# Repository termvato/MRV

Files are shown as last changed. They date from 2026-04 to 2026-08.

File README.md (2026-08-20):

# Monopedal Reconnaissance Vehicle (MRV)

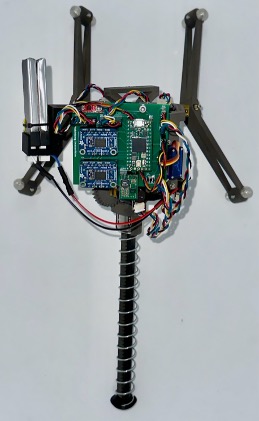
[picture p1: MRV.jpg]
MRV


A spring-loaded monopedal hopping robot stabilised by dual-axis reaction wheels, designed as a proof of concept for low-gravity exploration. Please read Dissertation.pdf for in depth development.

Developed as a BEng Mechanical Engineering thesis at the University of Warwick (ES327), supervised by Dr. Chris Purssell. Inspired by UC Berkeley's [SALTO](https://doi.org/10.1126/scirobotics.aag2048).

https://github.com/user-attachments/assets/57d9b59d-b111-4331-9489-9ee04b618cc3

https://github.com/user-attachments/assets/74c44a05-26f5-4240-8d7b-2275602fc39d

---

## Specifications

| Parameter | Value |
|---|---|
| Mass | 360 g |
| Jump height | 41.1 cm ± 1.2 cm |
| Release efficiency | 67.8% |
| Max recovery angle | 12.7° (bang-bang, full extension) |
| Energy recovery | 26–41% (height dependent) |
| Spring | 324 N/m, 11.5 cm stroke |
| MCU | Teensy 4.0 (600 MHz ARM Cortex-M7) |
| IMU | LSM6DSV16X (SFLP hardware fusion, 120 Hz) |
| Motors (jump) | 2× 298:1 geared DC |
| Motors (stabilisation) | 2× 50:1 geared DC |
| Battery | 2× 3.8V LiHV (7.6V) |
| Structure | SLS Nylon 12 |
| Counterweights | Lead-free pewter, cast in PPS-CF moulds |

---

## How It Works

The robot stores elastic potential energy in a compression spring via a rack-and-pinion driven by two geared DC motors. Asymmetric sawtooth teeth on the rack enable self-tightening meshing by redirecting outward shear inwards. In combination with wedges the robot ratchets passively on landing, recovering landing energy without motor power or fast control loops. A servo-actuated cam releases the driven gear from the rack, allowing the spring to extend and launch the robot. 

Two orthogonal reaction wheel arms provide pitch and roll correction during flight. Each arm carries a 42 g pewter counterweight at 79 mm radius, driven by a 50:1 geared DC motor. A 1 kHz safety ISR disengages the arms if attitude exceeds 45°.

---

## Test Results

| Test | Result |
|---|---|
| Jump height (mean of 3 valid trials) | 41.1 cm ± 1.2 cm |
| Theoretical max jump height | 60.6 cm |
| Release efficiency | 67.8% |
| Jump reliability | 4/7 (57%) |
| Launch tilt | 32° in 0.28 s |
| Recovery angle (bang-bang) | 6.8°, 10.7°, 12.7° ✓ / 14° ✗ |
| Energy recovery (50 cm drop) | 26.1% |
| Energy recovery (100 cm drop) | 40.9% |
| Unsymmetric wedge improvement | +38% stored energy |

---

## CAD

All CAD files are available in the FUSION folder in this repo.

---

## Hardware

| Component | Part | Role |
|---|---|---|
| Microcontroller | Teensy 4.0 | ARM Cortex-M7 at 600 MHz |
| IMU | LSM6DSV16X (SparkFun Micro 6DoF) | 6-axis, SFLP hardware fusion, I²C |
| Arm encoders | PIM604 quadrature (×2) | Arm angle, velocity, acceleration |
| Speed encoders | PIM604 quadrature (×2) | Shaft RPM for drive motors |
| Arm motor driver | TB6612FNG dual H-bridge | Drives two arm motors. STBY = safety cutoff |
| Spring motor driver | TB6612FNG (channels paralleled) | Drives spring winding motor |
| PCB | Custom 4-layer (JLCPCB) | 30 mil traces per IPC-2221A |

---

## Repository Structure

```
MRV/
├── AGENTS.md
├── Dissertaion.pdf
├── LICENSE
├── README.md
├── platformio.ini
├── src/
│   ├── main.cpp
│   ├── config/
│   │   └── config.h
│   ├── hardware/
│   │   ├── pinout.h
│   │   ├── imu.h / imu.cpp
│   │   ├── encoder.h / encoder.cpp
│   │   └── motor_driver.h / motor_driver.cpp
│   ├── math/
│   │   ├── quaternion.h / quaternion.cpp
│   │   └── filters.h / filters.cpp
│   ├── state/
│   │   ├── robot_state.h / robot_state.cpp
│   │   └── state_estimator.h / state_estimator.cpp
│   └── comms/
│       └── serial_reporter.h / serial_reporter.cpp
├── tools/
│   ├── visualise_imu.py
│   └── visualise_imu.html
├── models/
│   └── model.obj
├── PCB/
│   ├── Schematic.pdf
│   └── MRV.epro
└── docs/
    ├── BOM.csv
    ├── CODEBASE_GUIDE.md
    └── photos/
```

One responsibility per file. The IMU file knows nothing about serial output. The serial file knows nothing about quaternion maths.

---

## Getting Started

### Flash the firmware
1. Install [PlatformIO](https://platformio.org/) in VS Code.
2. Clone this repo and open the project folder.
3. Connect Teensy 4.0 via USB.
4. Build and upload:
   ```
   pio run --target upload
   ```
5. Open serial monitor at 115200 baud:
   ```
   pio device monitor
   ```

### Run the visualiser
**Browser (recommended):** Open `tools/visualise_imu.html` → click Connect → select the Teensy serial port. Requires a Chromium-based browser with WebSerial support.

**Python:** Install dependencies and run:
```
pip install pyserial numpy matplotlib
python tools/visualise_imu.py
```

---

## Serial Output Format

One line every 100 ms (10 Hz):

```
T:1234567 | Q:0.00123,0.00456,-0.00012,0.99998 | RPY:0.14,0.52,-0.03 | J:12.3,88.6,0.0 | K:5.40,12.30 | S:120.5,0.0
```

| Field | Description |
|---|---|
| `T:` | Timestamp (µs) |
| `Q:` | Quaternion x,y,z,w |
| `RPY:` | Roll, pitch, yaw (degrees, ZYX Euler) |
| `J:` | Joint angles: ARM0, ARM1, LEG (degrees) |
| `K:` | ARM1 angular velocity (°/s) and acceleration (°/s²) |
| `S:` | Speed encoder RPMs |

Safety events: `SAFE:1` (motors cut) / `SAFE:0` (cleared via `SAFE_CLR`).

---

## Commands

Send via serial from the visualiser or terminal:

| Command | Action |
|---|---|
| `ARM:127` | Set arm motor speed (-255 to 255) |
| `SPR:200` | Set spring motor speed (-255 to 255) |
| `SAFE_CLR` | Re-enable motors after safety cutoff |

---

## Detailed Codebase Guide

For a complete file-by-file walkthrough of every module, data structure and design decision, see [`docs/CODEBASE_GUIDE.md`](docs/CODEBASE_GUIDE.md).

---

## Inspired By

- [SALTO](https://doi.org/10.1126/scirobotics.aag2048) — UC Berkeley Biomimetic Millisystems Lab
- [Jumper](https://doi.org/10.1038/s41586-022-04606-3) — UC Santa Barbara
- [CUBLI](https://doi.org/10.1109/pedestrians.2013.6496012) — ETH Zurich

---

## License

MIT License. See [LICENSE](LICENSE).

---

## Author

**Vakhtang Inasaridze** — University of Warwick, 2026

Continuing at UC Berkeley MEng Mechanical Engineering.

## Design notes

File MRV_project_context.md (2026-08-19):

# MRV Project — Context for New AI Chat

## What this is
Teensy 4.0 embedded firmware for a robotic system, plus a browser-based 3D visualiser.
Build system: PlatformIO. Project root: `/Users/vato/Documents/MRV/MRV_code`.

---

## The OBJ file — `models/model.obj`

**Format:** ASCII WaveFront OBJ, exported from Autodesk Fusion (ATF exporter). 408,289 lines.
Companion material file: `models/model.mtl`.

**Coordinate system:** Z-up (Autodesk convention). The Three.js visualiser applies
`wrapper.rotation.x = -Math.PI / 2` to convert Z-up → Y-up (Three.js convention).
After this rotation, the robot's vertical axis is Three.js Y (green).

**Overall Z extent in OBJ space:** −8.54 (foot bottom) to ~25.7 (top of ARM(1)). Total height ~34 units.

**Pivot point used in visualiser:** foot bottom at OBJ coordinates `(-0.079, 0.048, -8.507)`.
This is negated and applied as `obj.position` so the foot sits at the wrapper origin — the robot
rotates about its ground contact point. A slider controls the Z component live.

**Materials used:**
- `Steel_-_Satin` — structural metal parts
- `Brass_-_Matte` — gears
- `ABS_(White)` — plastic body panels
- `Nylon_6-6_(White)` — bearings/joints
- `EPX_86FR_(with_Carbon_M2_M3_L1_3D_Printers)` — carbon composite parts
- `Glass_(Blue)` — transparent cover
- `Paint_-_Metallic_(Black)`, `Paint_-_Metallic_(Dark_Grey)` — painted parts
- `Opaque(203,210,239)` — PCB

---

## All 32 mesh groups

| OBJ group name | Role | Centroid (x, y, z) | Z range |
|---|---|---|---|
| `Body1` | Main body panel (right side) | (2.24, −1.59, 11.76) | 11.26–12.26 |
| `Body1:1` | Body sub-part | (−4.58, −1.63, 18.18)  | 17.72–18.64 |
| `Body1:2` | Body sub-part (main lower) | (0, 0, 9.16) | 7.76–10.56 |
| `Body1:3` | Body sub-part | (0, 5.08, 17.06) | 16.56–17.56 |
| `Body1:4` | Body sub-part | (5.08, 0, 17.06) | 16.56–17.56 |
| `Body1:5` | Main body panel (left side) | (−2.24, −1.59, 11.76)  | 11.26–12.26 |
| `Body1:6` | Body sub-part | (0, −3.56, 14.21) | 12.59–15.84 |
| `Body2` | Main chassis — largest part (15k verts) | (0, 0, −0.21) | −8.54–8.11 |
| `ThinBearing` | Thin bearing race | (−1.19, −1.30, 14.79)  | 14.44–15.14 |
| `ARM` | **Left arm** — encoder not yet wired | (8.49, 0, 17.06) | 16.31–17.81 |
| `ARM (1)` | **Right arm** — active encoder on pins 20/21  | (0, 8.49, 17.06) | 8.38–25.74 |
| `WEIGHT` | Counterweight on ARM (left) | (10.09, −7.95, 17.06)  | 15.63–18.49 |
| `WEIGHT2` | Counterweight on ARM (left) | (10.09, 7.95, 17.06) | 15.63–18.49 |
| `WEIGHT2 (1)` | Counterweight on ARM (1) (right) | (0, 10.09, 9.11) | 8.59–9.64 |
| `WEIGHT (2)` | Counterweight on ARM (1) (right) | (0, 10.09, 25.01) | 24.49–25.54 |
| `ConRod L` | Left connecting rod | (−1.56, −0.76, 13.26)  | 11.48–15.04 |
| `ConRod R` | Right connecting rod | (1.56, −0.76, 13.26) | 11.48–15.04 |
| `ConRodwSpring L` | Left connecting rod with spring | (−1.68, 0.81, 13.13) | 11.23–15.04 |
| `ConRodwSpring R` | Right connecting rod with spring | (1.68, 0.81, 13.13) | 11.23–15.04 |
| `DriverGear (1)` | Drive gear (right) | (2.24, 0, 11.76) | 10.17–13.36 |
| `DriverGear (1) (1)` | Drive gear (left) | (−2.24, 0, 11.76) | 10.17–13.36 |
| `DrivenGear` | Driven gear | (1.99, −0.01, 14.72) | 13.12–16.32 |
| `DrivenGear (1)` | Driven gear (second) | (−1.99, −0.01, 14.72)  | 13.12–16.32 |
| `CROWN` | Crown gear (large, 3361 verts) | (0, 0.53, 14.02) | 10.33–17.70 |
| `DriveMotorMount` | Motor mount bracket | (0, −2.17, 11.48) | 10.56–12.40 |
| `Struct` | Main structural cross-member | (0, 0.78, 9.77) | 7.53–12.01 |
| `LEG` | Vertical slide / leg (14k verts, full Z span) | (0, 0, 5.78) | −7.61–19.17 |
| `Foot` | Foot platform | (0, 0, −8.01) | −8.51–7.51 |
| `BALL (1)` | Ball foot contact | (0, 0, −8.34) | −8.89–7.80 |
| `DriveMotorMount` | Motor mount bracket | (0, −2.17, 11.48) | 10.56–12.40 |
| `PCB` | Circuit board | (−3.34, −2.52, 15.58)  | 12.55–18.60 |
| `PCB_Mount` | PCB mount bracket | (−4.08, −1.14, 18.14)  | 17.70–18.57 |
| `PCB_Mount2` | PCB mount bracket (second) | (−1.91, −3.31, 18.14)  | 17.70–18.57 |

**Critical naming gotcha:** Autodesk exports group names with spaces before parentheses.
In Three.js `traverse()` you must match `child.name === 'ARM (1)'` (with a space), not `'ARM(1)'`.
Same applies to `DriverGear (1)`, `WEIGHT2 (1)`, `WEIGHT (2)`, `BALL (1)`, etc.

---

## Arm rotation — how it works in the visualiser

**ARM (left arm)** rotates about its own bounding-box centroid. Implementation:
```javascript
const armBox    = new THREE.Box3().setFromObject(arm1Mesh);
const armCenter = armBox.getCenter(new THREE.Vector3());
const armPivot  = new THREE.Group();
armPivot.position.copy(armCenter);
obj.add(armPivot);
[arm1Mesh, ...weightMeshes].forEach(mesh => {
  mesh.position.sub(armCenter);  // keep visual position unchanged
  armPivot.add(mesh);
});
arm1Mesh = armPivot;  // animate the pivot
```

- **WEIGHT** and **WEIGHT2** follow ARM's rotation (arm counterweights).
- **WEIGHT2 (1)** and **WEIGHT (2)** belong to ARM (1) — not yet animated.
- Rotation applied in render loop:
  `arm1Mesh.rotation.x = -(arm1AngleDeg + arm1CalibOffset) * Math.PI / 180`
- Negated because the encoder direction and model direction are opposite.
- `arm1CalibOffset` is set on Calibrate: `arm1CalibOffset = ARM1_INIT_DEG - arm1AngleDeg`

---

## Firmware — file structure

```
platformio.ini
src/
  main.cpp                    # setup()/loop() only — no hardware access here
  config/config.h             # ALL constants (constexpr only, no #define magic numbers)
  hardware/
    pinout.h                  # ALL pin numbers — nowhere else
    imu.h / imu.cpp           # LSM6DSV16X SFLP driver
    encoder.h / encoder.cpp   # Joint + speed encoder driver
  math/
    quaternion.h / .cpp       # Quaternion struct + ZYX Euler decomposition
    filters.h / .cpp          # stub (unused)
  state/
    robot_state.h / .cpp      # RobotState struct — data contract between all modules
    state_estimator.h / .cpp  # IntervalTimer sets flag; tick() does I2C in main loop
  comms/
    serial_reporter.h / .cpp  # Rate-limited Serial output
tools/
  visualise_imu.html          # Single-file Three.js visualiser (no build step)
models/
  model.obj / model.mtl       # Robot 3D model
```

---

## Key design decisions

- **IMU:** LSM6DSV16X hardware SFLP fusion — no software Madgwick/Mahony.
  PlatformIO lib: `stm32duino/LSM6DSV16X`.
  I2C address `0x6B` (SA0=1, SparkFun Qwiic breakout default).
  FIFO drains to the most-recent sample. `IntervalTimer` sets a `volatile bool` flag only;
  actual I2C read happens in main loop (never in ISR).
- **All constants:** `constexpr` in `config.h`. All pins in `pinout.h`. No magic numbers elsewhere.
- **Bus selection:** `// #define USE_IMU_SPI` in config.h (commented = I2C).
- **No heap allocation:** all drivers use module-static objects (`static Encoder s_arm1(...)`).
- **State flow:** `StateEstimator::tick()` reads IMU + encoders → populates `RobotState` →
  `SerialReporter::update()` prints it at the configured rate.

---

## Encoder hardware and config

### ARM (1) — right arm, ACTIVE

- Hardware: Pimoroni PIM604 Rotary Encoder Breakout
- Pins: 20 (A), 21 (B)
- Library: paulstoffregen/Encoder (hardware quadrature interrupts on Teensy 4.0)
- **DO NOT change these without re-tuning:**
  - `ENC_ARM1_COUNTS_PER_REV = 12.0f` — nominal 96 CPR but empirically only 12 effective
    counts/rev (possibly single-channel wiring or non-standard PPR)
  - `ENC_ARM1_GEAR_RATIO = 50.0f`
  - Scalar `359.32f` in the angle formula — manually tuned
  - Formula: `degrees = count × 359.32 / (ENC_ARM1_COUNTS_PER_REV × ENC_ARM1_GEAR_RATIO)`
- Initial calibration position: **90°** (`ENC_ARM1_INIT_DEG = 90.0f`)

### ARM — left arm, NOT YET WIRED

- Guarded by `// #define USE_ARM0_ENCODER` in config.h (commented out)
- Pins: `PIN_ENC_ARM0_A/B` — left as `???` in pinout.h, fill in when wired
- Placeholder constants (tune empirically when wired):
  - `ENC_ARM0_COUNTS_PER_REV = 12.0f`
  - `ENC_ARM0_GEAR_RATIO = 50.0f`
  - `ENC_ARM0_SCALAR = 360.0f`
- Initial position: **0°** (`ENC_ARM0_INIT_DEG = 0.0f`)

### Speed encoders — shaft RPM only, no position tracking

- `s_spd2`: pins 14 (A) / 15 (B)
- `s_spd3`: pins 16 (A) / 17 (B)
- Both PIM604, `ENC_SPEED_COUNTS_PER_REV = 96.0f`
- Formula: `RPM = (delta_count / 96) × (60 / dt_seconds)`

---

## Velocity/acceleration computation (encoder kinematics)

Uses a **sliding-window velocity estimator** + **EMA filter** in `JointEncoders::update()`:

1. A ring buffer (`_angleHistory[joint][ENC_VEL_WINDOW]`, `_timeHistory[ENC_VEL_WINDOW]`)
   stores the last `ENC_VEL_WINDOW = 10` **raw (unwrapped)** angles and timestamps.
2. `rawVel = (angle_now − angle_oldest) / window_dt` — averages quantisation noise over ~83 ms at 120 Hz.
3. `smoothVel = ENC_VEL_ALPHA × rawVel + (1 − α) × smoothVel_prev` — EMA, α = 0.10.
4. `acc = (smoothVel_now − smoothVel_prev) / one_tick_dt`

**Important:** The ring buffer stores the **unwrapped** (continuously accumulating) angle so that
velocity across a 0°/360° boundary computes correctly. The **reported** `_angles[1]` should be
wrapped to `[0, 360)` for display only. Kinematics must always use the unwrapped value.

Minimum detectable speed at 120 Hz with a 10-tick window: ~7 deg/s.

---

## Serial output format

Rate: `SERIAL_REPORT_RATE_HZ = 10` Hz (≤ `IMU_SAMPLE_RATE_HZ = 120`). Baud: 115200.

```
T:<us> | Q:<x>,<y>,<z>,<w> | RPY:<r>,<p>,<y> deg | J:<j0>,<j1>,<j2> deg | S:<rpm0>,<rpm1> | K:<vel_dps>,<acc_dps2>
```

| Field | Content |
|---|---|
| `T` | `micros()` timestamp — wraps at ~70 min, use difference arithmetic only |
| `Q` | Raw unit quaternion from SFLP engine, 5 decimal places |
| `RPY` | ZYX Euler angles in degrees derived from Q |
| `J` | Joint angles: [0]=ARM, [1]=ARM(1), [2]=LEG |
| `S` | Shaft RPM: [0]=spd2 (pins 14/15), [1]=spd3 (pins 16/17) |
| `K` | ARM(1) kinematics: smoothed angular velocity (deg/s), acceleration (deg/s²) |

---

## Visualiser — `tools/visualise_imu.html`

Single-file Three.js app, no build step. Open in Chrome or Edge (WebSerial API required).

- **Libs:** Three.js r0.164.1 via CDN importmap; OBJLoader, MTLLoader, OrbitControls
- **Serial:** WebSerial API, 115200 baud, line-buffered `parseLine()`
- **IMU rendering:** target quaternion slerp'd toward display quaternion each frame.
  Corrections applied: 45° yaw offset (IMU board mounting angle) + X/Y axis flip
  (`R_z(π)·q·R_z(π)` conjugation).
- **Calibration button:** zeroes IMU orientation AND resets arm visual to 90°.
- **Graphs:** two `<canvas>` elements fixed at bottom, declared before the overlay `<div>`
  in DOM order (controls z-stacking without explicit z-index):
  - Left 50%: ARM(1) angular velocity (red) — autoscaled y-axis
  - Right 50%: IMU Roll (red) / Pitch (green) / Yaw (blue) — fixed ±180°
  - 300-sample ring buffers ≈ 30 s of history at 10 Hz report rate
- **Sliders:**
  - Smoothing — quaternion slerp alpha
  - Pivot Z — which OBJ Z coordinate sits at the ground pivot (default −8.5 = foot bottom)

---

## What's confirmed working on hardware

- IMU quaternion → RPY at 120 Hz, displayed correctly in 3D
- ARM(1) encoder angle (manually tuned 359.32f scalar confirmed correct)
- Arm rotation direction correct in visualiser (encoder direction is negated)
- Calibrate button resets both IMU zero point and arm visual to 90°
- Speed encoders reading RPM on pins 14/15 and 16/17

## What's not yet wired / implemented

- ARM (left arm) encoder — `USE_ARM0_ENCODER` compile guard exists, pins TBD
- LEG encoder (joint index 2) — always 0° in firmware
- `WEIGHT2 (1)` and `WEIGHT (2)` mesh animation — belong to ARM(1), no encoder yet
- ConRod encoders (indices 3–5) — not in firmware
- IMU INT1 interrupt (Teensy pin 2) — unused, IMU is polled not interrupt-driven

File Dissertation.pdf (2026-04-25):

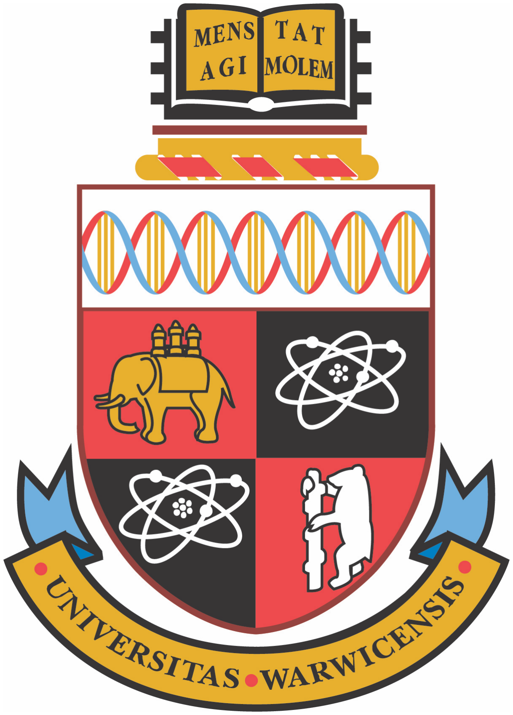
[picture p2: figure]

# Saltatorial Robotics as a Method of Exploration

By

## Vakhtang Inasaridze

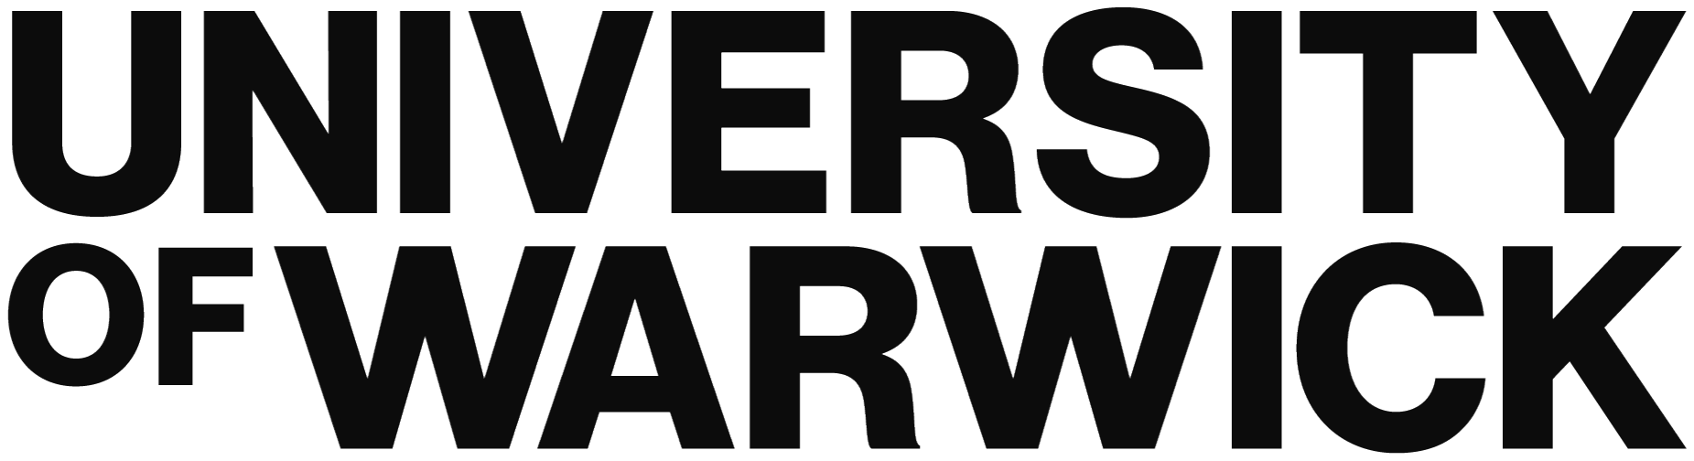
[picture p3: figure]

ii

## Table of Contents

iii

iv

References | a
Relevant Appendices | f

v

## List of tables and figures

Figure 1- Jumper self-righting sequence by COM displacement. [4] | 6
Figure 2- Annotated image of the final MRV prototype. Final IMU placement differs from image,
battery harness now includes a voltage divider circuit for battery monitoring | 8
Figure 3- Annotated close-up image of the key bearing mechanism. The mechanism is resisting leg
rotation hence the bearing is at an angle | 12
Figure 4-(A) Annotated side view of the MRV; (B) Annotated close-up image of the drive mechanism;
(C) Annotated CAD section of the drive mechanism; (D) Annotated CAD cross section of the leg and
driven gears | 13
Figure 5- (A) Annotated CAD screenshot of the release mechanism; (B) CAD screenshot of inserted
connections | 14
Figure 6- Annotated pewter casting process image | 15
Figure 7- Safety ISR loop, independently from the main loop hosts: red – interrupt timer, yellow – logic,
lavender – actuation, light blue – comms | 17
Figure 8- Software flowchart of the main loop: blue – initialisation, yellow – logic, green – sensor,
orange – tool, lavender – actuation, light blue- comms | 18
Figure 9- (A) Plotted data of drop height vs spring compression length with a linear trendline. (B) Plotted
data of energy recovery efficiency vs possible GPE with a linear trendline | 20
Figure 10- (A) Updated Gantt chart, before exam break. (B) Updated Gantt chart, after exam break..25
Figure 11- Screenshot of the budget management spreadsheet organised by subassembly | 27

Table 1- Success metrics, includes the measurement, respective objective, target result, mean of actual
results | 2
Table 2- Pugh decision matrix for servo energy release including rack, driver gear and driven gear out
of the way | 10
Table 3- Cumulative experimental results table including jump height, recovery angle and energy
recovery | 19
Table 4- Symmetric and unsymmetric wedge compression comparison table across three trials each. 21 Table 5- Project risk register containing name of risk, likelihood, impact, mitigation strategy and post
mitigation assessment | 26

Equation 1- Formula for gravitational torque in terms of mass, gravitational acceleration, CoM height
and inclination | 23

vi

Appendix Fig. 1- Original Gantt chart from PFS, before initial exam break | f
Appendix Fig. 2- Original Gantt chart from PFS, after initial exam break | f
Appendix Fig. 3- Schematic of the MRV colour coded. Light green: motor wires, dark green: encoder
signal, blue: directionality signal, pink: PWM, yellow: signal, red: power, black ground | g
Appendix Fig. 4-.3D render of the manufactured PCB from within EasyEDA. The PCB design used
headers for modularity and DuPont connectivity | h
Appendix Fig. 5- PCB schematic of the MRV. Blue: bottom layer, high voltage lines, green: ground
layer traces, olive: motor output and misc., red: signal wires | h

vii

## Acknowledgements

The author would like to thank project supervisor Chris for his guidance and feedback throughout the project, Kirill Kolotilin for his assistance during experimental testing, and the Engineering Build Space staff for their support with manufacturing facilities. Thanks also to Daniel Akula, Vittorio Ruffo di Calabria and Paolo Batistella for their helpful discussions throughout the project.

viii

## Abstract

The Monopedal Reconnaissance Vehicle or MRV is a prototype jumping robot using dual inertial actuators in orthogonal axes and a spring-based propulsion system. The goal of the project is to develop and demonstrate a novel robotic mobility platform aimed at low gravity exploration. This report outlines the research, design, testing and analysis conducted as a BEng mechanical engineering individual project. Results of this report include research that can form the basis of future deployments such as required energy balances, mechanical and sensory considerations. The final prototype achieved a jump height of 41 cm as a 360 g mass. Using 11.5 cm of compression and a 324 N/m spring, the robot achieved a jump efficiency of 67.8% and 26% landing energy recovery. A maximum single-axis recovery angle of 12.7° was demonstrated using bang-bang control. Deliverables are planned to be published and include all necessary files for reproduction in a github repository under the MIT open-source license. These include CAD, software tools, hyperlinked BOM, detailed design processes and experimental methodology. Results demonstrate that dual-axis inertially stabilised monopedal hopping is feasible, with mechanical refinement identified as the path to improved reliability and energy sustainability.

ix

## Abbreviations

MRV – Monopedal Reconnaissance Vehicle

IMU – Inertial Measurement Unit

PID – Proportional Integral Derivative

LQR – Linear Quadratic Regulator

MPC – Model Predictive Control

PFS – Project Feasibility Study

SLS – Selective Laser Sintering

PLA – Polylactic Acid

PCB – Printed Circuit Board

PWM – Pulse Width Modulation

CoM – Centre of Mass

EBS – Engineering Build Space

SFLP – Sensor Fusion Low Power

GPE – Gravitational Potential Energy

EPE – Elastic Potential Energy

PiP – Print in Place

PTFE – Polytetrafluoroethylene

RPM – Rotations Per Minute

MCU – Microcontroller Unit

1

## 1. Introduction

### 1.1 Context and motivation

Jumping is a locomotion strategy attractive for small robotic systems due to its ability to convert stored energy into impulsive vertical thrust, enabling traversal of rough terrain and obstacles without continuous ground contact. In evolutionary terms, saltatorial animals such as the red kangaroo (Macropus rufus) achieve up to 70% energetic efficiency by recovering landing energy in tendons for use in the next jump [1]. Inspired by this principle, robotic jumpers can potentially act as efficient and lightweight scouts in environments where wheeled systems are limited by steps larger than the radius of their wheels and flight is constrained by power or atmospheric conditions. This paradigm mirrors the reconnaissance role demonstrated by NASA’s Ingenuity, which executed terrain scouting flights ahead of the ground Perseverance rover [2], [3].

However, many currently available mechanisms prioritise take-off performance and mechanical simplicity over attitude control, which leads to poor reliability and low directional control throughout the motion [4], [5]. This project investigates the development of a Monopedal Reconnaissance Vehicle (MRV) that lies at the intersection of bio-inspired efficiency and modern control theory. This single leg jumping robot includes elastic energy storage in the form of a spring and uses dual inertial actuators to stabilise the body about two orthogonal axes. This project evaluates whether controllable, repeatable monopedal hopping stabilised by dual-axis inertial actuators is technically feasible.

### 1.2 Problem specification

The following specification was derived from the conducted project feasibility study (PFS):

Build a monopedal robot stabilised by two orthogonal inertial actuators, with the ability to perform a repeatable launch, store a portion of landing energy and release it for the subsequent jump. Develop and implement a controller to perform attitude stabilisation and jump actuation of the robot to evaluate the robot using the success metrics in Table 1.

The PFS established a target jump height of 1 m, estimated robot mass of 150 g, a spring constant of 294 N/m and a 10 cm compression length. These parameters were the starting point for the design.

### 1.3 Aim

The aim of this project is to evaluate the technical feasibility of controllable, repeatable monopedal hopping stabilised by dual-axis inertial actuators. This includes the design and manufacture of an integrated electromechanical platform, development of an energy recovery mechanism and experimental characterisation of jump performance and attitude stabilisation capability.

2

### 1.4 Objectives

O1.Construct an electromechanical platform capable of vertical jumping, validated by Table 1 O2. Develop a mechanical design that maximises energy efficiency through recovery of landing energy and reduction of friction losses.
O3. Design and integrate dual inertial actuators about orthogonal axes and demonstrate 2-axis attitude stabilisation.
O4.Implement and experimentally tune a control algorithm for attitude stabilisation suited to the system's degrees of freedom.

### 1.5 Success metrics

Table 1- Success metrics, includes the measurement, respective objective, target result, mean of actual results.
Metric | Objective | Target | Mean result
Release efficiency | O1, O2 | Maximise | 67.8%
Energy recovery ratio | O2 | Maximise 26.1-40.1%
Maximum recovery angle | O3, O4 | 45º | 12.7º
Jump reliability | O1 | Maximise | 57%

### 1.6 Scope and limitations

The contribution of this report is to outline the development process of monopedal jumping robotics and its interface with dual inertial actuators as the attitude control method. For control, the MRV is treated as two modes: stance (leg is in ground contact) and flight with impact treated as a disturbance. Control is implemented experimentally using a tuned controller rather than derived from a first-principles dynamics model, with model-based approaches such as LQR recommended as future work. Success of this project would yield key functionality like a stable stance at varied leg extensions, repeatable hop execution, landing energy recovery and respective measured data recorded in Table 1. Development of mechanical structures, electrical systems and controlling software enabling main functionality is considered in scope of the project. While designing the robot, specifications are drawn from its future potential use case in scientific exploration in environments such as the moon. As in all developments aimed at space, simplicity, reliability, cost, form factor and mass are considered and optimised throughout. Deliverables include full BOM, CAD models, schematics, experimental methodology, prototype and test design for future research replication.

Environmental effects are not considered in design but are discussed. These effects include radiation, dust accumulation, terrain variance, thermal cycling and effects of long-term use. Environmental hardening is therefore not conducted. End of life disposal considerations including material recyclability and battery handling are discussed in Section 7. Translational locomotion, path planning or other

3

dynamic sequences are not attempted however are part of recommended future work along with FE and impact analysis which could potentially improve final functionality. Parameters are estimated from the CAD mass properties and leverage manufacturer datasheet readings. Tests include physical constraints such as bearings for 1-axis stabilisation and cable capture for jump tests which may affect the readings and introduce uncertainty that is acknowledged and minimised where possible.

The project was proposed and approved through a PFS submitted in Term 1, which established initial objectives, budget, timeline and component specifications. Given the budget and the overall 24-week schedule with 4 weeks allocated to integration, testing and write-up, priority is given to demonstrable stabilisation capacity and quantifiable jumping.

## 2. Literature Review

Jumping as a locomotion strategy is not a novel idea with research by NASA into hopping transporters for lunar exploration citing dates as far as 1967 [6]. A similar research question to this report’s has been posed as the original Lunar Pogo Stick concept in 1967 where its use was considered for human transport [7]. Benefits of hopping such as energy efficiency, exploitation of weak gravity and independence from smooth terrain are highlighted in research of The Lunar Hopping Transporter [8]. Paradigms such as energy recovery and stabilisation are discussed as upon landing a piston is discussed to partially compress with energy replacement through pneumatics [8]. This parallels the energy recovery and replacement approach investigated throughout this report. These ideas were aimed at being sent with the Apollo missions, similar to this project’s targeted Artemis program [9]. Notably, these research papers were heavily limited by their reliance on human command in the absence of current advanced computational, sensor and actuation suites.

### 2.1 Hopping robots and energy storage

Hopping or jumping is a movement that utilises impulsive, intermittent ground contact to exert control and impulse to enter a desired flight phase. In contrast, walking gaits or roving can exhibit a force throughout the motion by staying in ground contact and having the ability to actuate at any point in time. Multiple methods to achieve hopping or jumping exist and are as follows.

Pneumatics, leverage gas compression and pressure forces in order to provide the necessary impulse to propel the robot. The research paper that inspired projects like the Jax [10] by Marc Raibert for ‘Dynamically stable legged locomotion’ [11] heavily rely on compression propulsion, usually with a switch on the foot of the robot controlling actuation. This actuation method is attractive due to its high peak power and impulse density, determined by stored pressurized gas. In addition, simplicity of actuation such as a valve enables efficient release of stored potential energy. Implementation of a gas

4

storage system is its main drawback. Where electricity can be slowly built back up using a solar panel, an autonomous robot that runs out of compressed air is immobilized until a manual recharge. Complexity in pipefittings and safety arise from practical execution of the propulsion method and therefore is not implemented [12].

Inertial impulse hopping, achieved by instantaneously decelerating a spinning disk, is another method to achieve a jump. The angular impulse is translated along the body of the robot to a pivot point that swings the robot into air. This has been demonstrated in field by MASCOT on the Hayabusa 2 mission on an asteroid for data collection and as a proof of concept [13]. Attractiveness of this design stems from the shielding that comes with a fully enclosed robot without exposed mechanics and reduced complexity. However, the robot does not exhibit a controlled nature and samples the surface at random with a stated minimum of two hops. Therefore, inertial hopping is not to be used as the propulsion strategy.

Furthermore, elastics have been used in similar applications due to their inherent high energy density and implementation simplicity. Notable example of this is the record-breaking Jumper by UC Santa Barbara that uses engineered carbon fiber and polymer composite rods under elastic buckling to store and release energy launching the robot 30 m vertically [4]. SALTO is another highly agile monopedal robot that relies on elastic energy storage in the form of a torsional polymer spring and actuation through an 8-bar linkage, translating rotation to a vertical impulse [14]. Given the inherent energetic advantages, elastics are an attractive choice for a small-scale, lightweight reconnaissance robot. In addition, elastics such as springs, exhibit a predictable nature through linear approximations like Hooke’s law and therefore can be modelled and hence sourced to a specification. This is the chosen strategy given its feasibility and low risk due to the abundance of suitable prefabricated springs on supplier websites such as Lee Spring [15].

### 2.2 Energy release

Following storage of potential energy, a mechanism must exist to release it in a sudden controlled burst. Pneumatic solutions use valves connected to external compressed gas supplies. These are limited by the flowrate and require almost instantaneous opening, otherwise the robot does not experience a large enough acceleration to enter flight and instead simply displaces upwards. Approach of the Jumper is to use a winched string system that upon fully loading, physically triggers a release that drops and unwinds the tensioned cable at once. This means that the robot must wind to the limit to execute a jump as the latch does not trigger on command, making it a binary energy release mechanism. To remedy this, it would be possible to add a small actuator such as a servo to open the latch on command. However, this extra complexity and mass would surely reduce the maximum jump height. SALTO does not use a latch and instead relies on timing torque output from a brushless motor during ground contact to further

5

tension the spring during ground contact. This requires fast control loops and a custom polymer spring attached to an encoder to measure its deflection. While this is a highly mass efficient design and allows a dampened landing through precise motor control, the robot must build up height in a series of jumps in order to reach its maximum height each time, wasting energy. For a reconnaissance mission requiring stationary measurements, this continuous hopping cycle would result in energy loss between jumps. It would increase efficiency and therefore range, if storage and on-command triggering of elastic potential energy is designed for.

For high-risk missions like extraterrestrial exploration, where reliability is paramount, a design principle of minimising complexity is held. Where the Jumper excels is in its low part count and minimal design, so that it lands by direct landing impact [4]. Absence of complex control algorithms, IMUs or other stabilisation actuation greatly reduces the number of failure points and limits power consumption to primary function. With this in mind, the design of the MRV energy system must be mechanical, for passive actuation, and aim to use minimal number of components reducing possibility for failure [5].

Based on the available research, the MRV is to be designed with a vertically displacing leg accommodating spring compression. In mechanics, a ratcheting mechanism is able to limit the direction of input displacement to one axis [16]. A mechanism for ratcheting the leg would enable storage of potential energy recovered from landing and result in a stationary stance at the point of largest spring compression. Along with a method of on-command energy release, this would make the MRV a controllable and inherently efficient vehicle for scientific exploration.

### 2.3 Stabilisation

As discussed previously, the MRV is to utilise a leg for its propulsion. This means that to direct its jump it is required to execute a jump at an angle. Moreover, to record measurements such as photographs or temperature, it would be optimal that the robot remains stationary [18]. Stabilisation, as discussed here, is correction of the robot’s body from a trajectory that might result in immobilisation or damage.

Due to flight being a significant portion of a jumping sequence, it is unsurprising to see numerous developments use propelled thrusters to either stabilise such as SALTO [19] or gain altitude like the Hopcopter [20]. In SALTO’s case, geometry of the robot and the presence of a large reaction wheel forced the team to use propellers to overcome physical limitations of orthogonal reaction wheels hitting each other. Thrusters are also a mass-efficient actuator, the motor assembly on SALTO that enables roll and yaw control and weighs less than 7 g [21]. For the purpose of this report, propelled thrusters are not considered as a viable stabilisation method due to atmospheric conditions on the moon or similar celestial bodies with low gravity. There remain three other common stabilisation methods: pneumatic

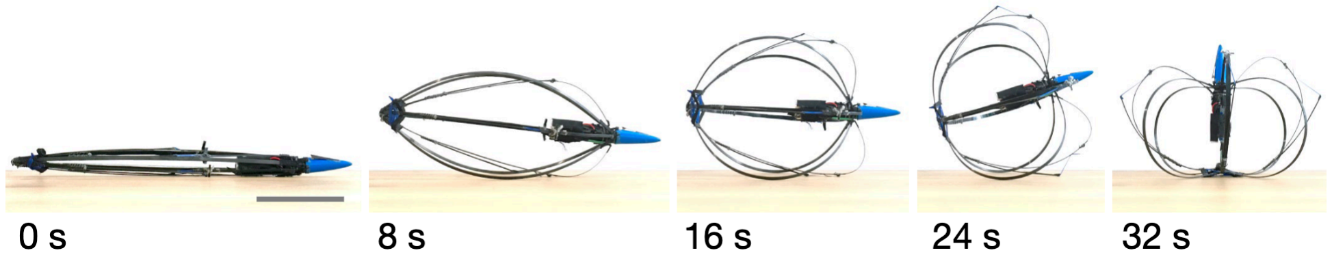
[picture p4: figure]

6

thrusters, ground stabilising sequences such as used by the Jumper and reaction wheel based inertial stabilisation.

Pneumatic thrusters work on the principle of momentum conservation. By storing and releasing high pressure air, the robot moves in the direction opposite to airflow. Similar to propulsion, pneumatics is not considered further due to the need for manual recharging of air canisters and leakage risks [12].

Ground stabilising sequences are movements designed to leverage a structure in order to regain initial position. For example, the self-righting sequence that Jumper utilised is shown in Figure 1. These offer an electro-mechanical solution to the stabilisation problem with the requirement of ground contact. Need for complex control electronics and algorithms are eliminated by designing a structure that can exhibit a passively stable nature. This paradigm governs the design of a significant part of the Jumper robot and does not add the ability to direct itself. Benefits such as energy efficiency, that arise from stabilising as a side effect of loading the spring are overshadowed by the robot always returning to the same position. Given the nature of the landing and inhomogeneous surfaces present in exploratory environments, the robot may end up jumping in unpredictable directions. Therefore, this method is not used in the MRV.

Figure 1- Jumper self-righting sequence by COM displacement. [4]
Reaction wheel stabilisation relies on rotational impulse generated by accelerating masses at a radius. Examples of use include the DEMETER satellite [22] and the CUBLI [23] which use reaction wheels to control their attitude. Given the nature of the chosen propulsion method, an elastically loaded leg, the robot would be considered as an inertially stabilised inverted pendulum, as in the ‘Self-Balancing Stick’ by Mike Rouleau [24] and [25]. This method adds complexity to the mechanism and control algorithms. In addition, sensory electronics such as an IMU and encoders would therefore be required along with more actuators such as motors following current research. A reduction in runtime is expected as stabilisation becomes an active task, in contrast to self-righting, using up more of the battery power. On the other hand, the robot would gain a dynamic controllable nature with a future possibility of remote command execution. Moreover, it eliminates issues regarding ground contact and dependence on atmospheric conditions. Reaction wheel stabilisation is therefore selected as the attitude control method for the MRV.

7

### 2.4 Control approaches

Having chosen dual-axis reaction wheels as the stabilisation method, a control strategy for their real-time activation is required. Projects with a similar approach use several control algorithmssuch as linear-quadratic-regulator (LQR) in CUBLI and Belascuen et al. [23], [26]. This method involves the parametrisation of the system by finding its inertial masses, motor constants and damping factors. This information is then converted into a state-space representation of the system for use in software like MATLAB to derive a LQR seed gain. This process has shown to stabilise a reaction wheel based inverted pendulum in work such as by Witczak et al. [27]. They cover the implementation of LQR and PID into an experimental inverted pendulum set up. The work concludes that LQR offers superior disturbance rejection, though it requires an accurate linearised model of the system.

Model predictive control offers constraint handling and prediction over a horizon but requires solving an optimisation problem at each time step, posing a computational burden unsuitable for resource-constrained embedded systems typical of small-scale and small-budget robotics [28].

Proportional-integral-derivative (PID) is a commonly used controller that involves tuning three values representative of the magnitude, sum and rate of change of the error. Its use eliminates the need to derive complex mathematical models of the robot, instead relying on experiments to hand tune these values. Example of a successful project using PID is Rouleau’s Self Balancing Stick, which is a dual axis inertial actuator stabilised inverted pendulum, matching the MRV [24].

The scope of the project is demonstrating feasibility of the mechanical platform. PID allows immediate experimental tuning without complex parameter identification and mathematical model derivation. Unlike the systems studied by Witczak et al., the MRV involves variable inertia with leg extension, nonlinear friction across multiple gear interfaces and backlash in the drivetrain. Accurate characterisation of these parameters within the planned test window is not feasible, making model-based approaches impractical for this project. Moreover, PID has been shown to be successfully deployed on comparable dual reaction wheel systems such as Rouleau’s stick discussed earlier [24].

### 2.5 Gap statement

As discussed in this literature review, hopping robots such as Jumper and SALTO prioritise propulsion without active attitude control. CUBLI and Rouleau demonstrate stabilisation without locomotion. No existing work has been found combining dual-axis inertial stabilisation with elastic energy storage and ratcheted landing energy recovery on a monopedal hopping platform. This project contributes experimental investigation of this combination.

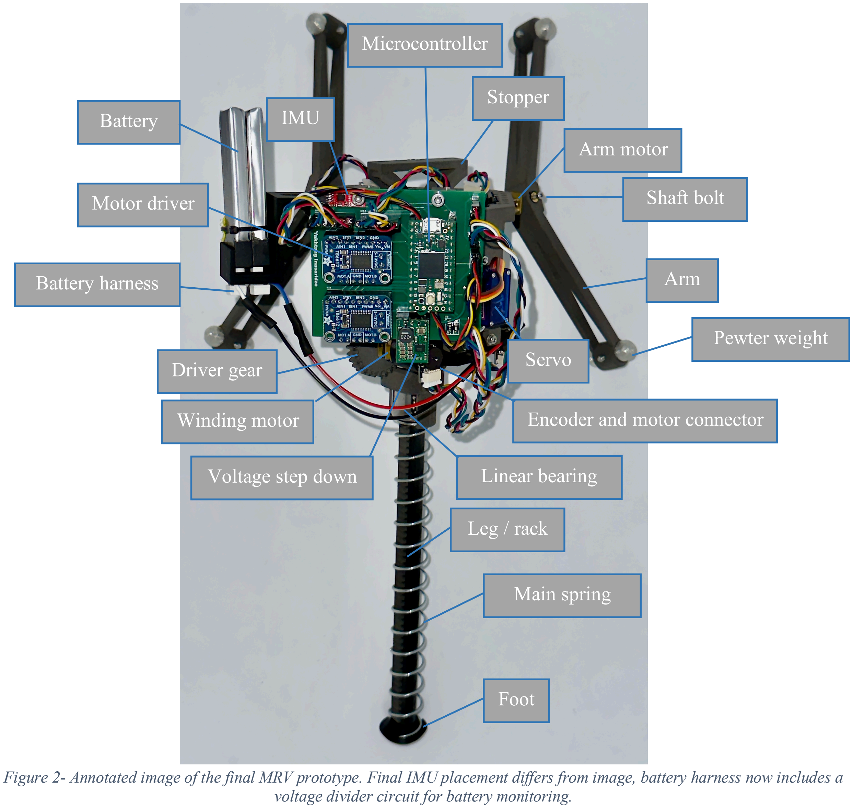
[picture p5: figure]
Pewter weight; Arm; Arm motor; Main spring; Foot; Leg / rack; Servo; Stopper; Battery; Battery harness; IMU; Driver gear; Winding motor; Motor driver; Linear bearing; Microcontroller; Voltage step down; Shaft bolt; Encoder and motor connector

8

## 3. Design method

### 3.1 System overview

The MRV is treated as an assembly of three interconnected subsystems: propulsion, stabilisation and control. These are discussed in detail in following subsections and can be seen in Figure 2. The final design of the propulsion system includes the structural components and mechanisms responsible for energy release and recovery such as the leg, gears, ratchet, spring and linear bearing. Stabilisation consists of the two arms with end masses driven by motors to achieve counter rotation in the robot. Lastly, the control subsystem encompasses the electronics that record measurements from the IMU and encoders, execute a control algorithm driving the actuators.

Figure 2- Annotated image of the final MRV prototype. Final IMU placement differs from image, battery harness now includes a voltage divider circuit for battery monitoring.

9

### 3.2 Design evolution

Revision A: Motor selection and torque-speed trade-off
During the PFS for the proposal of the MRV project, a requirement for a 30N spring force came about. The PFS concluded that 1.5 J of stored elastic energy was required for a 1 m jump at 150 g, achievable with a k=294 N/m spring compressed over 10 cm. To accommodate this and convert angular motor torque into linear displacement, a rack and pinion-based design was considered. From the PFS it was also concluded that it was beneficial to maximise compression length x to leverage 2nd order displacement variable in the elastic energy equation !"! = !
"

$%". This would allow the robot to store

most energy with the least winding force, reducing internal structural stress and motor torque requirements. A compression length of 10 cm was chosen from the PFS with wind time to be 0.5 seconds, enough to fully compress it during flight. Gears were specced to fit in the robot’s approximate dimensions, manufacturing method and circumference requirement. 1.5 cm radius gear was assumed, based on which leg motors could be sourced. Given the assumed gear, the motor must exhibit a minimum torque of 0.45 Nm and 127 RPM to compress 10 cm in 0.5 sec. Given budget and timeline limitations, custom wound motors such as in SALTO were not considered. Brushless and geared DC motors were compared with most cost-torque effective found to be the 1006:1 geared DC motor (COM0802).

The motor fit the torque requirements with a 4 N margin of safety. However, produced 14.2 RPM. At 14.2 RPM with a 1.5 cm radius gear, the motor compresses the spring by 1.1 cm per 0.5 sec flight, storing only 0.018 J per cycle. While the initial jump can take longer to wind up, subsequent jumps maintaining height would require a mechanism with 98.8% efficiency given initial spring energy of 1.5
J. This efficiency is not practically achievable given typical mechanical and motor efficiencies [29].

This demonstrated that gear ratio must be reduced to increase shaft speed at the cost of torque, leading to the adoption of dual, lower ratio motors.

Revision B: Dual motor configuration and symmetric loading
Prioritising shaft speed, the 298:1 (COM0801) motors were selected. The new motors produce 2.5 kg·cm of torque and 72 RPM compared to 5.3 kg·cm and 14.2 RPM of the COM0802 [30], [31]. At 1.2 rps, the motors compress the spring by 5.6 cm in 0.5 seconds, exceeding the 5 cm required assuming 50% energy recovery from landing. Solution to the lack of torque was to use two 801 motors either side of the rack combining to 5.0 kg·cm, comparable to the 1006:1 motor's 5.3 kg·cm. Having driver gears on two sides of the rack also means that the rod’s shear forces are symmetric, therefore they negate and reduce lateral frictional losses improving efficiency.

10

In both revision A and B, the angled gear teeth allow the vertical spring force to push the gears out of mesh. A structure that holds the motors must withstand the sideways force and maintain gear meshing. This results in an increased stiffness requirements and risks material fatigue from force cycling.

With both designs in revision A and revision B, the motors are geared. This means that they produce a significant resistance to free-spin and would limit the release of the leg in terms of speed and efficiency. A solution to this is a release mechanism.

Revision C: release mechanisms
Prioritising simplicity, a missing-tooth gear design was explored first. Essentially, the release would happen when the gears rotated through to a section without teeth to mesh with the rack and therefore allow the spring to extend. Having built and tested a 3D printed prototype, the performance of the mechanism was adequate. The gears meshed with the rod enough to hold a spring with significantly higher stiffness than in the final design. From experiments, it was noted that the spring could only release when a full revolution was completed. This was a binary energy output and meant that the spring released either all the energy or none. This prompted research into variable energy release mechanisms from literature and common mechanisms.

Several alternative release methods were explored including expanding starter mechanisms, one-way bearings, rack displacement and extendable teeth. Each suffered from the same fundamental barrier: the mechanism must simultaneously resist spring force during storage and allow free motion during release. No purely mechanical variable energy release mechanism suitable for the project constraints was identified. Electromechanical solutions were then considered, compiled in the Pugh matrix in Table 2.

Table 2- Pugh decision matrix for servo energy release including rack, driver gear and driven gear out of the way.

Criteria
+ better, - worse, 0 same

Missing tooth
(datum)

Rack
out of way

Driver gears
out of way

Driven gears
out of way
Energy variability | 0 | + | + | +
Controllability | 0 | + | + | +
Manufacturability | 0 | - | - | -
Dynamic coupling | 0 | - | 0 | 0
Stationary actuator | 0 | + | - | +
Mech. simplicity | 0 | - | - | -
Energy efficiency | 0 | - | + | +
Structural load bearing | 0 | - | - | +
Total | 0 | -2 | -1 | +3

11

From Table 2 a ‘driven gears out of the way’ release mechanism scored highest and was therefore selected. The driven gear approach combined variable energy release with stationary actuator mounting and structural load isolation, justifying the added mechanical complexity.

Revision D: Ratcheting energy and sawtooth design
Selection of the driven gear release mechanism enabled further energy conservation features. In line with objectives, the mechanism would be benefited by a ratcheting leg. As mentioned previously, this would store recovered potential energy in a passively stable form. Gear directionality could have been implemented by using one-way bearings or a jam rod with a spring. Prioritising mass and budget conservation, one-way bearings were eliminated. This left the spring with jam rod option which would fold the rod in one way, compressing the spring, and push down the jam rod the other way, limiting rotation. This would have required a stiff structure and four more springs, for symmetric rod folding.

To eliminate components, a jamming wedge with compliant print in place (PiP) springs was designed. Cutting down on four springs and reducing the mass of the jamming component. The PiP springs were designed as a single part with the connecting rod between driver and driven gears reducing part count seen in Figure 4 (B). Moreover, is facilitated the wedge to be pushed out of the way in one direction and catch the teeth in the other direction.

Now that the gears ratchet the motors do not do any work holding up the leg while it is in a charged position. However, to store landing energy or ratchet the leg upwards precise servo control from state-estimation to open the gears before landing and catch the robot at its lowest point was considered. This would have required fast feedback and actuation loops, beyond the prototyping capabilities.

A passive solution was once again required to let the leg ratchet upwards. Leveraging knowledge of the lateral forces from leg downward force a teeth design with steep angles was thought of. The idea that given vertical force the teeth would be pushed out of meshing was here utilised. Moreover, the fact that teeth design was now in research, led to the discovery of a shear-less tooth design. In which the lateral forces affecting gear meshing and structural stiffness are eliminated by angling the teeth asymmetrically. This produced a gear teeth design that allows passage when landing, meshes with gears and does not produce lateral forces when winding. Design is seen in Figure 4 (C) and is reminiscent of a sawtooth.

Revision E: Material selection and tolerancing
Throughout prototyping, manufacturing methods and materials have been considered. For initial conceptual prototypes such as the missing tooth, PLA was used. Tolerances and geometric fits were validated using rapid iteration on the Bambulab X1 in the EBS. During preliminary assembly, a snap to

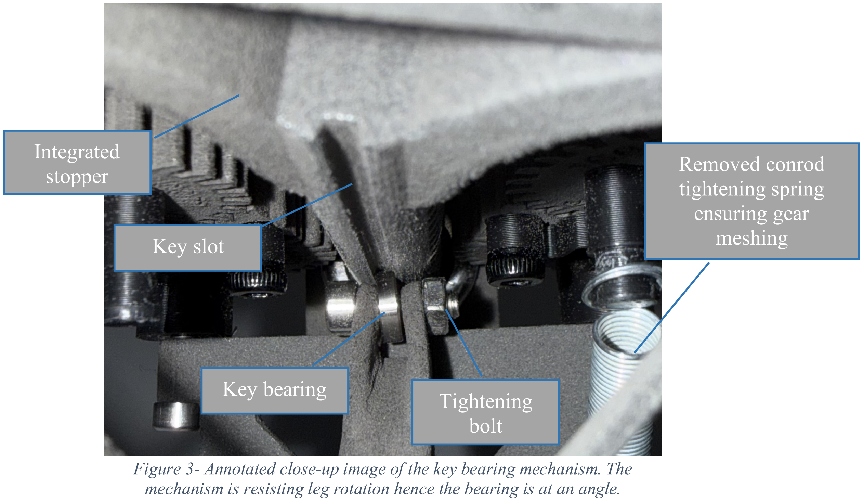
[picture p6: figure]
Key bearing; Removed conrod tightening spring ensuring gear meshing Key slot; Integrated stopper; Tightening bolt

12

fit leaf broke off when the linear bearing was inserted. Analysing the fault, it was evident that the breakage happened along layer lines. Moreover, when printing the leg, the manufacturing method required it to be split into a two-part print to have a flat build plate contact surface. This manufacturing method led to a concave leg from gluing and forced an increase in part count, such as the stopper being separate. Selective laser sintering (SLS) was therefore adopted, a process that fuses nylon powder layer by layer without supports, producing homogeneous and isotropic parts. Although nylon exhibits lower stiffness than PLA, its toughness and resistance to brittle fracture make it more suitable for the repeated impact loading experienced during jump cycles. Dimensional tolerances differed from PLA, requiring resizing of mounting holes and adoption of M2 threaded inserts for reliable fastening. SLS nylon's isotropic strength enabled the linear bearing leaf, stopper to be integrated directly into their respective parts, reducing component count and eliminating glue joints as failure points. This improved maintainability by allowing the entire leg to be reprinted and swapped without full disassembly.

Design summary
Through five revisions, the design evolved from a single high-ratio motor with a missing-tooth release to a dual-motor, cam-actuated, ratcheting system in SLS nylon. Each revision addressed a specific failure: insufficient shaft speed (A), asymmetric loading (B), binary energy release (C), absence of passive energy recovery (D) and brittle material failure (E). The resulting design satisfies the original objectives of variable energy release, passive ratcheting and repeatable actuation while remaining within the £300 budget. The final mechanical, electrical and software subsystems are detailed in the following sections.

Figure 3- Annotated close-up image of the key bearing mechanism. The mechanism is resisting leg rotation hence the bearing is at an angle.

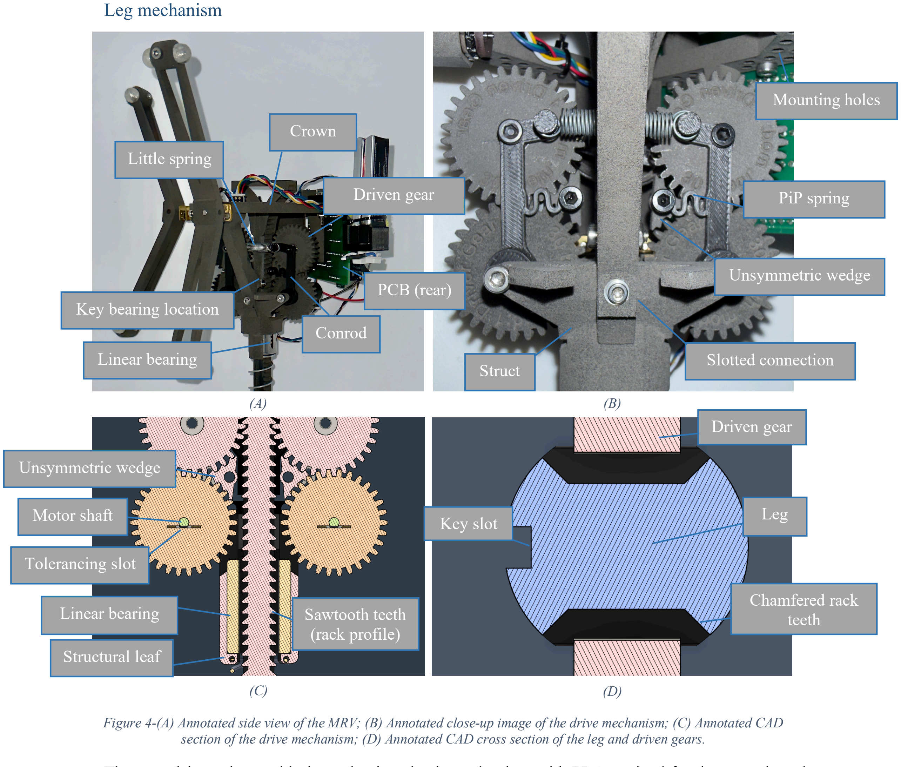
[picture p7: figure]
Leg mechanism; Little spring; Conrod; Driven gear; Unsymmetric wedge; PiP spring; Key bearing location; PCB (rear); Motor shaft; Tolerancing slot; Structural leaf; Linear bearing; Sawtooth teeth; (rack profile); Key slot; Chamfered rack teeth; Leg; Mounting holes; Slotted connection; Crown; Struct Linear bearing

13

### 3.3 Final mechanical design

The propulsion subassembly is predominantly sintered nylon, with PLA retained for the conrods and motor mount. A linear bearing (KH12) was used to ensure reliable and smooth vertical motion of the leg by interfacing at the cylindrical section visible in Figure 4 (A) and (C). Internal diameter of the bearing, 12 mm, constricts the diameter of the leg and the width of the teeth. The maximum compression stroke is 11.5 cm, constrained by the leg length and bearing travel. A key slot, visible in Figure 4 (D), interfaces with a thin key bearing, seen in Figure 3, to prevent rotation of the leg about the vertical axis, maintaining gear alignment. The width of the rack teeth is larger than the width of the gear teeth. This

Figure 4-(A) Annotated side view of the MRV; (B) Annotated close-up image of the drive mechanism; (C) Annotated CAD section of the drive mechanism; (D) Annotated CAD cross section of the leg and driven gears.

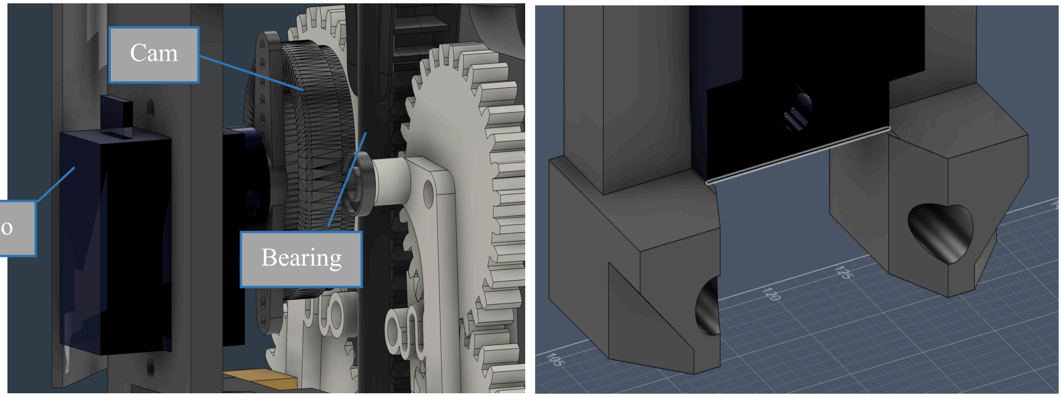
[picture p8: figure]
Cam; Bearing

14

is to aid re-meshing after a jump given some remaining play in the leg’s rotation. The downward angle of the sawtooth teeth allows passive ratcheting on landing while providing a vertical reaction force during winding, as discussed in Revision D. The gear modulus is tuned to be minimal while manufacturable through three iterations. This was to reduce the travel the servo would have to complete prior to releasing the spring. Consequently, this means a shorter time between signal and release aiding efficient actuation timing. The compression spring, visible in Figure 2, has a stiffness of 324 N/m and also serves to clamp the linear bearing leaves around the leg [32]. To prevent the spring from launching the leg away from the main body, the stopper was integrated directly into the leg increasing its strength. The foot is detachable by unscrewing a recessed bolt that connects via a threaded insert in the leg. The spring seats into a recess in the foot, retaining the foot if the bolt loosens.

Release mechanism
As selected in Section 3.2, the release mechanism relies on a 9 g servo. By mounting a cam to the horn of the servo, torque is translated into lateral force on the conrods. When the servo rotates, the cam profile pushes both conrods outward simultaneously, disengaging the driven gears from the rack and releasing the spring. To ensure smooth travel and meshing, thin bearings ride the cam and press against a lip to reduce the possibility of motor shaft bending. Each bearing is bolted down into the PLA conrod and can be seen in Figure 5 (A). After multiple revisions, the servo is mounted vertically with two points of contact. This is to aid in torque distribution from the servo overcoming the friction and slight angle in the driven gear and leg mesh. The shape of the insert, seen in Figure 5 (B), prevents the structure from applying shear force on the bolts that otherwise might break through the connection point wall. This insert approach is replicated at the crown-to-struct interface, creating three points of contact for structural rigidity. The conrods print in under 20 minutes, enabling rapid iteration of the bearing position to tune the mechanical advantage of the release.

Figure 5- (A) Annotated CAD screenshot of the release mechanism; (B) CAD screenshot of inserted connections.

Servo

15

Inertial actuators
The inertial actuators consist of two arms at orthogonal axes affecting pitch and roll. At a radius of 79 mm from the motor shaft, the arm is mounted to the shaft with a snug fit and an m2 bolt through a threaded insert digging into a flat portion of the motor shaft. These are manufactured from SLS nylon and have a weight reducing cut out. The arms are angled outward at 25º to maximise the 2nd order displacement from pivot variable in the inertia equation for point masses & = '(" and prevent arm collision. The arms include safety features such as safety bolts, to prevent masses from sliding out, and chamfered edges. These were included as a contingency to let the arms slide past each other during collision instead of the high impulse of two flat edges, potentially projecting the pewter masses.

The weights were manufactured using a low temperature pewter casting method. As seen in Figure 6, the mould was designed with manufacturability in mind. Made with carbon fiber-reinforced polyphenylene sulfide with a heat deflection temperature of up to 264°C [33]. It was printed with a high density, resulting in a weight of 130 g hence a high thermal mass to absorb heat away from contact surface preventing any mould deformation. The stems connect to the highest point of the masses, ensuring a full filling. A large funnel-like shape was implemented to serve as a buffer for filling, minimise metal spillage and prevent overfilling by being a larger visual sign. Four alignment pins can be seen in the corners of the mould ensuring a symmetric fit of the two-part mould. Rod inserts were designed to be hammered out to prevent complexities of odd object drilling such as custom clamp manufacture. Lead-free pewter was chosen due to its availability as a low temperature casting material, hazard considerations and density similar to that of steel making the volumetric CAD design straightforward. Moreover, it is a soft metal that can be postprocessed using common hand tools in areas such as cutting off the stems, trimming the overflow and filing the edges. Resulting counterweights and arm assembly weighed in at 42 grams, higher than the specced mass of 30 g from the PFS. This overshoot was done in order to ensure enough torque can be applied to the inertia, limiting the required rpm to 7 for a 90º correction. Given the softness of the mass material, unnecessary mass can be tuned rapidly.

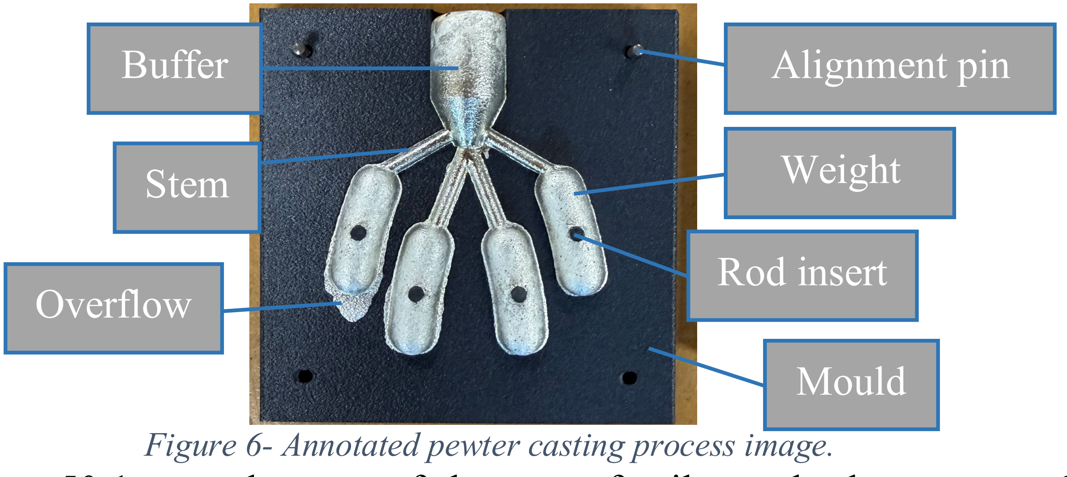
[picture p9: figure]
Rod insert; Mould; Stem; Buffer; Alignment pin; Overflow; Weight

Powering the arms is a 50:1 geared motor of the same family as the leg motors. Given the motor maximum torque of 3.92 Ncm and the estimated robot body inertia of 5.83 × 10⁻⁴ kg·m², the reaction wheel can theoretically correct a 45° disturbance in approximately 0.11 seconds [31]. This provides

Figure 6- Annotated pewter casting process image.

16

substantial control authority for the stabilisation task, with practical performance expected to be lower due to friction, back-EMF and motor speed saturation. As throughout the structure, the motors are snug fit and the rear soldered encoder mechanically prevents any potential for displacement out of the mount.

### 3.4 Electronics and sensing

Teensy 4.0 – MCU is the core of the control subsystem. Handles I/O of the sensor suite. For example, measures the change in angle per a unit of time to calculate the angular velocity of the arm motors ensuring saturation is not reached. Executes the control loop given input parameters from IMU and outputs actuation to the motor drivers or servo. Chosen for its low profile, low weight and fast processing frequency 600 MHz with option to overclock [34].

IMU (LSM6DSV16X) – a 6 degree of freedom inertial measurement unit, chosen for its high accuracy, onboard low power sensor fusion and small size. At 2.5 grams, the sensor fusion output drifts after high dynamic sequences, e.g. a jump. The yaw axis drifts 5.9º every 5 minutes which was a significant barrier during development and led to a repositioning that aligned the lesser drifting roll and pitch (1.2º, 1.6º per 5 mins) with the arm axes [35]. Drift is associated with the absence of a magnetometer as the chip is specifically specced to 6DoF due to absence of global magnetic fields on celestial bodies like the moon. The chip also features an ML core, uses of which can include jump cycle counting and tracking.

Motor drivers (Adafruit TB6612) – two motor drivers are used, driving two motors each. Per motor, they are capable of delivering 1.2 Amps. Receiving the higher 7.6 V supply directly from the batteries it is possible to modulate down to 6 V by limiting PWM to 77% duty cycle. The breakout board includes three inputs per motor, a PWM and two direction inputs to toggle the H-bridge. PWM is the output of the control algorithm running on the microcontroller [36].

Encoders (PIM604) – shares manufacturer with the motors and provides seamless motor driving and magnetic encoder integration. Solders to the back of the motor using the positive and negative connections. The protruding shaft is used to skewer a disk magnet that is read by the hall effect sensors at 12 counts per revolution [37].

Battery (BetaFPV LAVA) – Two 3.8 V 450 mAh LiHV cells connected in series provide a 7.6 V supply. Given the capacity and the 75 C discharge rate resulting in a maximum current output of 33.8 Amps, well above the required. With its 7.6 V, the battery would store approximately 7.6 V × 0.45 Ah × 3600 ≈ 12.3 kJ of energy enough for hundreds of jumps even at a low efficiency estimate [38].

Stepdown (D24V10F5) – converts the 7.6 V from the battery to a 5 V input for the teensy which then redistributes it to sensors suite and servo. The voltage regulator operates at a minimum 80% efficiency and supplies up to 1 Amp [39]. This is sufficient as only the logic circuitry and servo are operated through this. Motor power is drawn from respective drivers that have a separate battery connection.

PCB – ordered from a large manufacturer to a specification made in EasyEDA. Hosts all of the components apart from actuators and encoders. Acts as the motherboard for all circuitry Was completed to save mass from wires, breadboards and solder boards while reducing tangling risk. The PCB is four layers with a ground layer between the high voltage circuitry and sensor or control traces. Given the expected peak currents of up to 900 mA from motors, trace width was adjusted to 30 mils according to page 41 of IPC-2221A with a safety margin and maximum 10 ºC temperature increase [40]. Detailed schematic and PCB design can be seen in Appendix Fig. 3, Appendix Fig. 4 and Appendix Fig. 5.

### 3.5 Software architecture

Control logic of the MRV has been implemented in Visual Studio Code editor. Firmware is built using PlatformIO targeting the Teensy 4.0 with the Arduino framework. The project is structured using a modular file structure where one responsibility is assigned to each file. Architecture of the code consists of five modules: hardware, interfacing the IMU, encoders and motor drivers; math, for quaternion to Euler angle conversion; state, storing and estimating the current robot state; comms, transmitting data over USB serial; main, executing setup and the control loop. All constants are stored in a separate files, config.h and all pin assignments in pinout.h. This was done to ensure centralised correction in case of hardware changes, avoiding logic tampering.

An IntervalTimer triggers a sampling flag at 120 Hz, with I2C reads executed in the main loop to avoid bus conflicts during interrupts. Leveraging IMU built in functionality, the SFLP outputs quaternions at its maximum 120 Hz, hence the flag frequency. The outputs are then converted to Euler roll / pitch / yaw for human readability and control implementation. Encoders read shaft position via hardware quadrature interrupts that are converted to angle and velocity with acceleration for the arms. Safety cutoffs are implemented at 1 kHz independent of the main loop that disable the arm motors via the STBY pin when attitude exceeds 45°. Serial output is sent at 10 Hz for logging and visualisation. Logic flow can be seen in Figure 7 for the safety loop and Figure 8 for the main loop.

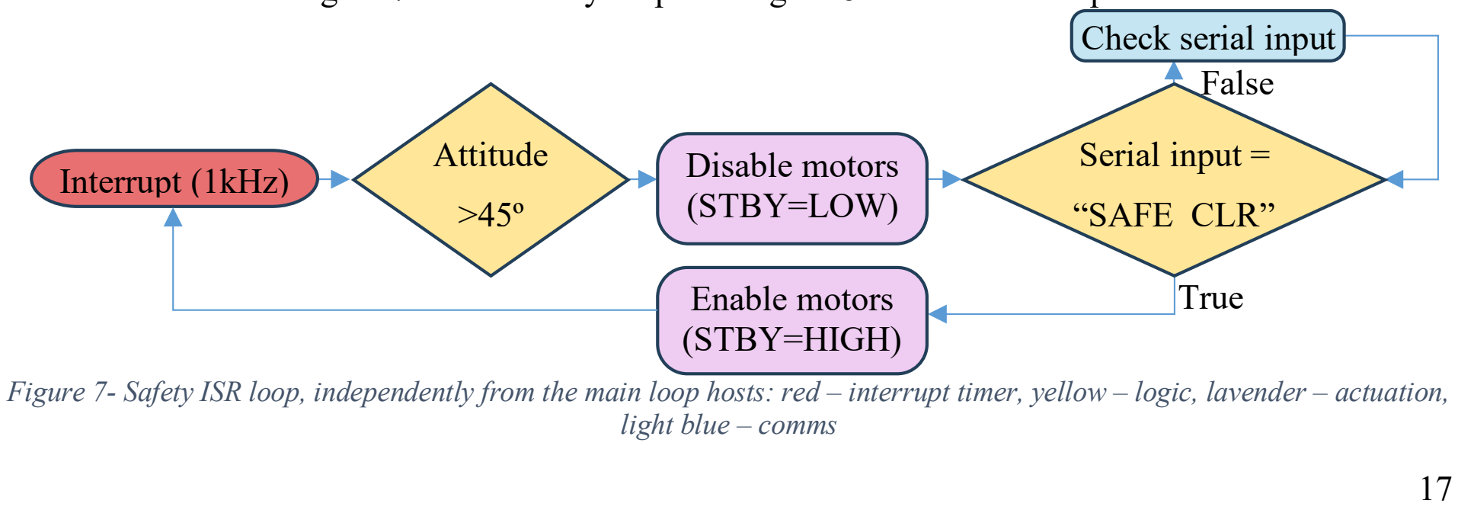
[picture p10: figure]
light blue – comms; Serial input =; “SAFE_CLR”; False; Enable motors; True; (STBY=HIGH); Attitude; Interrupt (1kHz); Disable motors; (STBY=LOW); Check serial input

Figure 7- Safety ISR loop, independently from the main loop hosts: red – interrupt timer, yellow – logic, lavender – actuation,

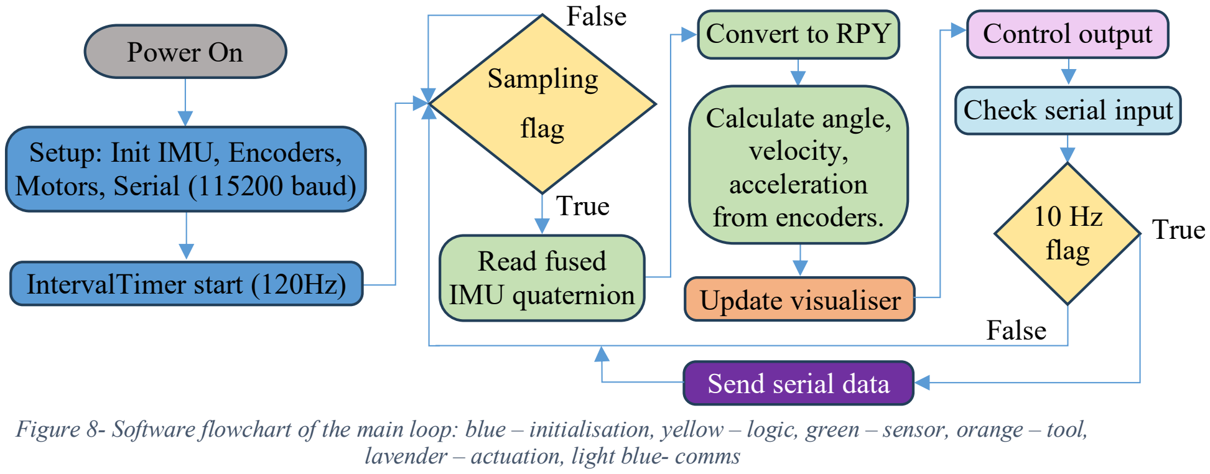
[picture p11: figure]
False; True; Sampling; flag; Update visualiser; Convert to RPY; Calculate angle, velocity, acceleration from encoders.; Power On; Setup: Init IMU, Encoders, Motors, Serial (115200 baud); IntervalTimer start (120Hz); Read fused IMU quaternion; Check serial input; 10 Hz flag; Send serial data; Control output; lavender – actuation, light blue- comms

18

### 3.6 Control implementation

Following the aims of the project, control strategies demonstrating the efficacy of the mechanical system were implemented. For maximum recovery angle characterisation, a bang-bang controller applying full motor torque in alternating directions was used to establish the upper bound of the hardware's stabilisation capability. A scaling gain proportional to leg extension was applied as the gravitational torque on the inverted pendulum increases linearly with the height of the centre of mass. The controller reads roll and pitch angles from the IMU at 120 Hz and outputs a PWM duty cycle to the respective arm motor driver limited to 77% (6V). PID control was implemented for continuous stabilisation, but tuning was deemed not feasible from lack of control authority. Bang-bang results hence represent the maximum achievable performance of the hardware, which a tuned PID controller would approach but not exceed.

### 3.7 Test plan and metrics

Test | Setup | Metric | Repeats
1-axis recovery angle | Rig with bearing | Max recovery angle | 4 angles
Maximum jump height | Cable capture, metre rule,
| slow mo, | Release efficiency | 4 trials
Energy recovery | Drop from known height, | Recovery ratio | 3 heights
ratio | measure compression
Maximum jump height – determines the largest obstacle the MRV could overcome extending its operating range. A slow-motion camera and meter rule is to be used around the robot performing a jump. A cable attached to the stopper of the robot is to be tightened by an assistant to prevent the effects of ground impact on repeat trials. Maximum displacement of the foot, not including in-flight leg compression, defines the jump height.

Figure 8- Software flowchart of the main loop: blue – initialisation, yellow – logic, green – sensor, orange – tool,

19

1-axis recovery angle – maximum attitude tilts the robot can achieve without falling. The larger the angle, the greater horizontal distance the robot can cover in a single jump with a maximum at 45º. This is to be measured using a rig that constrains the stabilisation to 1-axis and includes angle markings. The robot will start stationary at that angle and aim to accelerate the actuator in order to gain a vertical position at 0º. 2-axis stabilisation was planned but not completed and is recommended as further work.

Energy recovery ratio – amount of energy the motors need to add in order to achieve previous jump height after landing energy recovery as a ratio of initial energy. Simply dropping the robot from varying heights onto the foot and comparing the GPE to the stored elastic energy from a spring compression measurement. The robot is to ratchet the leg upwards and mesh he gears to catch the spring at the point of most compression. Ratio is then calculated as stored energy over available energy.

## 4. Results

Table 3- Cumulative experimental results table including jump height, recovery angle and energy recovery.
Maximum Jump Height Maximum Recovery Angle | Energy recovery
42.4 cm | 6.8º | from 50 cm: 53.09 mm
40.1 cm | 10.7º | from 75 cm: 73.21mm
23 cm | 12.7º | from 1 m: 94.42 mm
40.8 cm | 14º (fail)

### 4.1 Jump height

To measure the efficacy of the spring propulsion system, battery powered jump tests were carried out. The MRV struggled to jump on numerous occasions with the drive mechanism bending from servo actuation without releasing the leg. This is primarily associated with the high static friction in the leg rack and gear meshing. Moreover, the cam mechanism did not reliably manage to release both gears at the same time. From post-test analysis it was the centrality of the cam affecting the displacement of each conrod that led to one of the gears being left on the leg before release. On occasion, as was deduced from the third jump height entry in Table 3, the servo released the leg without providing enough clearance to prevent rubbing. A ratchet like noise was heard during the test which confirmed the cause. Only successful launches were recorded with a reliability of 4 launches out of 7 attempts (57%). Excluding the 23.0 cm trial attributed to gear rubbing, the mean jump height was 41.1 ± 1.2 cm across three successful trials. Given the controlled leg compression of 11.5 cm and the resulting theoretical potential energy limit of 2.14 J, the release reaching 1.45 J of gravitational potential energy with a release efficiency of 67.8%.

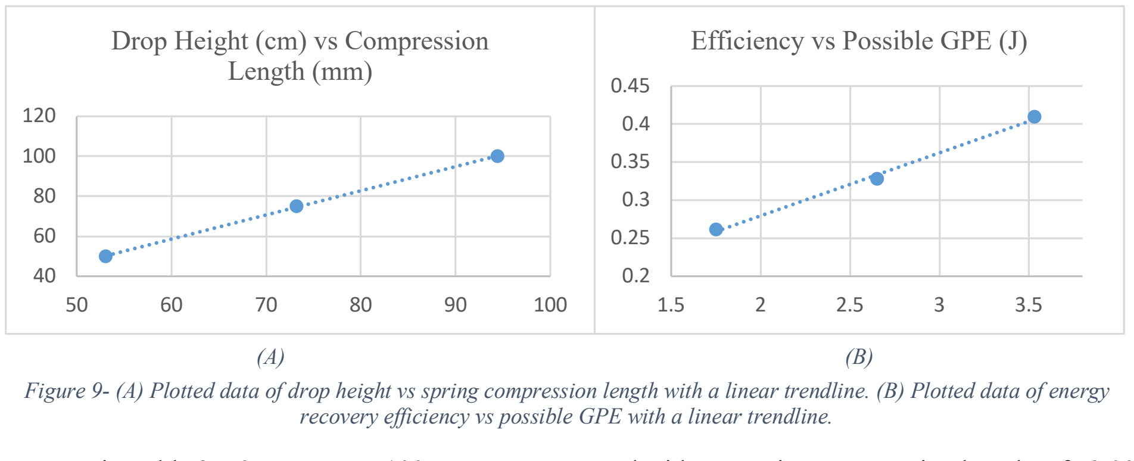
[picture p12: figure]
Drop Height (cm) vs Compression Length (mm); Efficiency vs Possible GPE (J)

20

During jump tests, the robot exhibited a coupled rotational displacement on launch, visible in slow-motion footage, attributed to asymmetric gear release timing. The tilt was approximately 32° from vertical at the jump vertex.

### 4.2 Recovery angle

Measurement of the recovery angle was conducted on a rig constrained by two bearings and a foot attachment with a shaft. Bang-bang control was utilised to find the mechanically bound maximum recovery angle. The robot was placed at test angles on the rig; motors were spun up to the upper limit clockwise and then instantly commanded to spin maximally anticlockwise. This generated the largest inertial impulse. The robot started from a stationary angular displacement; this was done to improve experimental controllability ensuring accurate angle measurement. The robot was considered to have recovered if it crossed the vertical equilibrium position. Four angles were tested with a maximal recovery angle of 12.7º and failing at 14º as seen in Table 3. In practice, the dynamic recovery angle during a jump would be significantly smaller as the robot must also overcome existing angular velocity from the disturbance. At 12.7°, the gravitational restoring torque approaches the maximum motor torque of 0.039 Nm, indicating a hardware-limited rather than control-limited result.

### 4.3 Energy recovery

The robot was dropped from ranging heights onto the leg. Compression was captured by the ratcheting mechanism reliably during all trials and the resulting spring compression was recorded. Three tests of different release heights were conducted to measure the efficacy of the energy recovery mechanism. Plots of which including a linear trendline can be seen in Figure 9 (A) and (B).

As seen in Table 3: 50 cm, 75 cm, 100 cm were attempted with respective compression lengths of 53.09 mm, 73.21 mm and 94.42 mm. Calculated efficiencies were 26%, 32.7% and 40.9% respectively. Energy recovery efficiency increased with drop height, rising from 26% at 50 cm to 40.9% at 100 cm. The

Figure 9- (A) Plotted data of drop height vs spring compression length with a linear trendline. (B) Plotted data of energy recovery efficiency vs possible GPE with a linear trendline.

21

robot’s own jump at 41.1 cm is closest to the 50 cm test with 26% recovery. This suggests approximately 26% of landing energy would be recovered during normal operation.

### 4.4 Motor compression

To quantify the effect of incremental efficiency improvements ratcheting wedge geometry was optimised and tested. Symmetric and unsymmetric wedges were tested by commanding the leg motors to wind the spring until an equilibrium position where the ratchet mechanism caught the leg and measurements could be made. Results of three repeats can be seen for each geometry in Table 4, with unsymmetric wedges compressing on average 10 mm more than symmetric. This corresponds to 0.514 J and 0.712 J of stored elastic potential energy for symmetric and unsymmetric wedges.

Table 4- Symmetric and unsymmetric wedge compression comparison table across three trials each.
Symmetric wedge compression | 56 mm | 58 mm | 55 mm
Unsymmetric wedge compression | 66 mm 66 mm 67 mm

## 5. Discussion and Analysis

### 5.1 Release efficiency and friction losses

The results outlined in 4.1 are attributed to friction in the leg mechanism. Given that it is the only component in contact with the moving leg it must be targeted with lubrication or tighter tolerancing to improve the efficiency number. Another potential source of inefficiency is spring and leg friction. During compression tests and assembly dust accumulation was noticed on the spring. In combination with buckling, that the spring experiences under heavy compression, it is an indicator of frictional inefficiency scraping away at the leg. Both could be improved by using a lubricant suitable for polymers such as silicone grease with PTFE and is recommended for future testing.

Jump reliability at 57% is a result that was expected from the initial design of the double gear release mechanism. A significant cause of this is the cam mechanism that was not able to displace the two gears at the same time. Differences in static friction from initial gear meshing resists the displacement of the cam bending the conrods around the centreline and not releasing. This is worsened when one of the gears successfully de-meshes resulting in the full spring force pressing down on one gear further immobilising it. The gear rubbing is an effect of a slight centrality offset of the cam mounted on the servo; it was fixed by increasing the angular displacement of the servo. The mechanism successfully released in 57% of attempts, demonstrating the concept but highlighting the need for cam refinement.

The prototype is predominantly 3D-printed with experimentally determined tolerances, leaving significant room for dimensional refinement. In particular, improving CoM centrality would reduce the

22

jump-attitude coupling observed during testing. During jump tests the robot acquired a 32° tilt within 0.28 seconds of launch due to asymmetric gear release. While the rotational kinetic energy is negligible (0.001 J), the resulting attitude exceeds the measured 12.7° recovery angle. This means the robot cannot self-correct after landing without improving the release symmetry and must stabilise in air. Addressing the CoM centrality is therefore critical not only for energy efficiency but for landing survivability.

### 5.2 Recovery angle

Hardware created the upper bound recovery angle of 12.7º utilising a bang-bang. This is an output of the maximum torque the motors can provide. A tuned PID controller would approach this result but not surpass it. Moreover, the test was completed from stationary meaning no adverse velocity component had to be overcome which is not similar to expected use scenario. Continuing to consider the use case, the recovery angle might be sufficient as the targeted environments experience lower gravity. On the moon where gravitational acceleration is approximately six times lower, the same hardware would recover from substantially larger angles, supporting the intended off-world reconnaissance application.

Although the 32° launch tilt exceeds the ground-based recovery angle of 12.7°, in-flight correction is governed only by body inertia without gravitational torque. The estimated correction time of 0.13 seconds is within the 0.58 second flight window, suggesting that active in-flight attitude control could compensate for launch asymmetry. This estimate assumes instantaneous motor command authority and does not account for reaction wheel momentum reversal time.

The 12.7° recovery angle limits the lateral displacement achievable per jump. At 12.7° from vertical, the horizontal component of the jump is :;<(12.7°) = 22% of the vertical, meaning for a 41.1 cm jump only 9 cm of lateral travel is achieved. Moreover, any lateral displacement introduces additional energy overhead as the stabilisation system must correct the resulting attitude disturbance on landing, and the recovery mechanism recovers less, reducing the net energy available for subsequent jumps.

Notably, stabilisation while the spring is compressed would benefit from the lower centre of mass, reducing the moment arm and therefore the gravitational torque the actuators must overcome. This suggests that attitude correction should be prioritised during the stance phase before release. During normal operation, the robot is not expected to undergo stabilisation at full extension which gives rise to highest gravitational torque that the actuators have to overcome. The gravitational torque acting on the robot is shown in Equation 1 where L is the centre of mass height above the pivot which varies with leg extension. This linear dependence on L motivated the scaling gain paradigm applied to the control output, increasing actuator authority as the leg extends. At 50% leg extension the centre of mass height halves, reducing gravitational torque and increasing the estimated recovery angle to 25.4°, comparable to the 26° achieved by Belascuen et al. on a dedicated single-axis reaction wheel pendulum [26].

23

Equation 1- Formula for gravitational torque in terms of mass, gravitational acceleration, CoM height and inclination.
A = ' × B × C × sin(G)

### 5.3 Energy recovery

Figure 9 (B) shows that recovery efficiency reaches 41% at a 100 cm drop height. However, the robot's actual jump height of 41.1 cm corresponds to the 50 cm test condition where efficiency is only 26%. Energy recovery efficiency increases with drop height from 26% at 50 cm to 41% at 100 cm. This suggests a fixed frictional overhead in the ratchet engagement, which constitutes a larger proportion of the total energy at lower impact velocities. Extrapolating, efficiency would continue to increase with drop height but plateau as the fixed overhead becomes negligible relative to the total energy. However, given that the stored energy in the spring cannot surpass the 0.6 m theoretical limit this inefficiency must be eliminated and cannot proportionally minimised.

Key finding from energy recovery results is that the robot would not be able to maintain or increase jump height from initial in its current state. The energy balance reveals that the ratchet recovers approximately 0.377 J per landing while the motors add 0.712 J per winding cycle. Together this accounts for 1.09 J of the required 2.14 J, leaving a deficit of 1.05 J. Reducing the friction losses in the release mechanism would significantly improve this balance. This can be done by optimising frictional assemblies such as the ratcheting wedges. The unsymmetric wedge mechanism stores 0.712 J per motor cycle compared to 0.514 J for the symmetric design, a 38% winding energy improvement from a minor geometric change. This validates the iterative refinement approach and demonstrates that small design modifications can meaningfully impact the energy balance. Improvement opportunities such as these are evident throughout the project such as linear bearing friction or changing the drive mechanisms gear-ratio to produce higher torque. They represent a systematic path to full energetic sustainability as in O2 which the current prototype does not achieve.

Existing robotics discussed in 2.1 do not host passive energy recovery mechanisms relying on constant hopping cycles. The recovery system adds friction losses during jumping. Further work must quantify whether the 26% landing energy recovery outweighs these additional losses.

### 5.4 Objective fulfilment

O1: The platform was fully designed, manufactured and assembled integrating mechanical, electrical and software subsystems. Testing confirmed vertical jumping at 41.1 cm mean height with 67.8% release efficiency. Launch reliability of 57% indicates the release mechanism needs refinement but the concept is demonstrated.

24

O2: Energy recovery of 26% was measured with a 1.05 J deficit per cycle. Full energetic sustainability was not achieved but a systematic path through friction reduction was identified. The mechanism demonstrated high reliability with the final iteration having recovered energy of every landing.

O3: Single-axis recovery was demonstrated with a 12.7° maximum recovery angle at full extension. Dual-axis testing was not completed as similar recovery performance is expected, in an offset axis.

O4: Bang-bang control was implemented establishing the hardware upper bound. PID tuning was attempted but not completed and is recommended as immediate further work.

Linking back to the aims and literature, the 41.1 cm jump height at 360 g corresponds to a jump height to mass ratio of 1.14 m/kg. For comparison, SALTO at 98 g achieves 1.25 m at 12.8 m/kg and Jumper at 30 g achieves 30 m at 1000 m/kg [4]. The MRV's lower ratio reflects its dual-purpose design carrying inertial stabilisation hardware and off the shelf components that pure jumpers do not. The 12.7° recovery angle compares to 26° achieved by Belascuen et al. [26] on a dedicated single-axis pendulum without propulsion hardware. The MRV achieves half this angle while also carrying a full propulsion subsystem, spring, ratchet and leg mechanism within the same mass budget. No comparable platform in the literature combines jumping, energy recovery and dual-axis stabilisation, making direct comparison difficult but indicating that the integration penalty is quantifiable and reducible through the improvements identified in this discussion.

### 5.5 Environmental considerations for deployment

The prototype validates the concept in terrestrial conditions. Deployment in the target lunar environment requires the following considerations:

1. Dust – lunar regolith is abrasive and electrostatically charged [41]. Exposed gears and linear bearing are vulnerable to entrap particles which can act as an abrasive, wearing the mechanism.
2. Thermal – lunar surface temperatures fluctuate between -173ºC and 127ºC. Nylon becomes brittle at low temperatures [42]. Differential expansion between metal and plastic components will affect tolerancing and might subject the structure to internal stress.
3. Radiation – Teensy 4.0 would require replacement or shielding to prevent damage.
4. Vacuum – no convective cooling for motors. PTFE lubricant outgasses in vacuum [43].
5. Gravity – 1/6th Earth’s gravity, as discussed in 5.2, scales up recovery angle and jump height which must be taken into consideration when designing a controller algorithm and IMU tuning.

Despite these challenges, the core design philosophy of mechanical simplicity, passive energy recovery and modular construction translates directly to a flight-hardened version. The bolt-on architecture and standardised threaded inserts would allow material substitution, such as titanium replacing nylon,

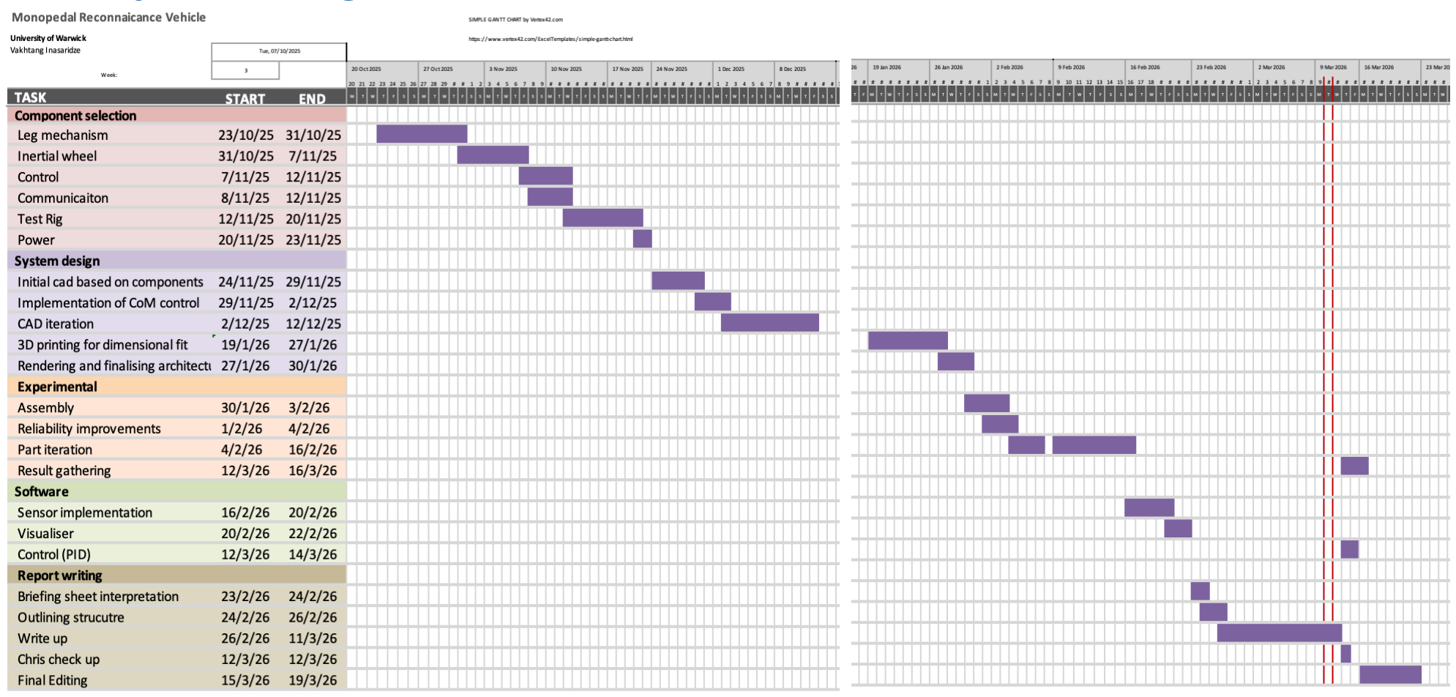
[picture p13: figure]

25

without a fundamental redesign of the mechanism geometry. These considerations are beyond the scope of the current project but are ranked in Section 8.3 as the final stage of MRV development.

## 6. Project Management

### 6.1 Timeline

Updated Gantt chart seen in Figure 10 omits a period between 12/12/25 and 19/1/26. This was in order to concentrate on exam preparation for other modules in the Mechanical Engineering degree. The original Gantt chart, from the PFS is included in Appendix Fig. 1 and Appendix Fig. 2. The PFS planned 8 weeks for control theory, 4 weeks for system design, 4 weeks for testing and 4 weeks for report writing. The current date is shown in red bars in Figure 10 (B). Key timeline adaptations include:

- Lengthened exam preparation period. Original 23/12/25 until 12/1/26. This meant system design was interrupted but continued post break. The reduced 18 days were re-distributed closer to the 19th of March deadline including the delayed experimental result gathering period.
- Software has been rescheduled to after experimental assembly and part iteration. Delays to PCB manufacture and need for correct hardware mounting was the cause. This necessitated a scope reduction from model-based control to experimentally tuned PID, prioritising demonstrable hardware functionality within the remaining timeline.
- Additional time was allocated for report writing which took significantly longer than the PFS anticipated, requiring over four weeks of concurrent writing alongside testing and design iteration. Despite these deviations, all four objectives were addressed within the 24-week timeline with no extensions requested.

Figure 10- (A) Updated Gantt chart, before exam break. (B) Updated Gantt chart, after exam break.

26

Progress was tracked through weekly supervisor meetings logged on Tabula, with scope and schedule adjustments discussed.

### 6.2 Risk register

A risk register was maintained and reviewed throughout the project. Key risks and mitigations are summarised in the following Table 5. The register was treated as a living document updated throughout the project as new risks were identified through prototyping. For example, cam asymmetry and IMU drift were not anticipated in the PFS but were added after being encountered during testing. The highest impact risk, not included in the table, was irreversible testing damage. It was mitigated by designing rapidly replaceable components such as conrods that print in under 20 minutes. No irreversible damage occurred during the project, validating modular design as an effective risk mitigation strategy.

Table 5- Project risk register containing name of risk, likelihood, impact, mitigation strategy and post mitigation assessment.
Risk | Likelihood Impact | Mitigation | Post mitig.
PCB manufacture
delay
Certain | Medium | Ordered early, time to order twice. | Medium

Motor torque
insufficient for
spring
Medium | High | The driver-driven gear ratio is
adjustable. Can maximise torque in exchange for RPM.

Low

IMU drift | High | High | Run calibration sequence every trial. Limit trials to 5 minutes.

Medium

Hardware dependency delay | High | Medium | Scope reduced to PID, simulation eliminated.

Medium

Exam period | Certain | Medium | Redistributed time after exam, | Medium
delays | | | postponed testing window.

### 6.3 Budget

A budget of £300 was allocated for the project. Figure 11 summarises expenditure by subsystem. The total spend of £286.66 represents 95.5% utilisation with £13.34 remaining. The largest cost driver was the electronics subsystem at £159.48, driven by PCB manufacture. Materials for 3D printing accounted for £57.83. No budget overrun occurred. The compression spring was obtained as a free sample from Lee Spring, reducing the total cost.

Component sourcing required coordination across five suppliers: Pimoroni for motors and encoders, JLCPCB for PCB fabrication, Pololu for the voltage regulator, Lee Spring for the compression spring and BetaFPV for batteries. Lead times ranged from 2 days (Pimoroni, UK) to 17 days (JLCPCB, China

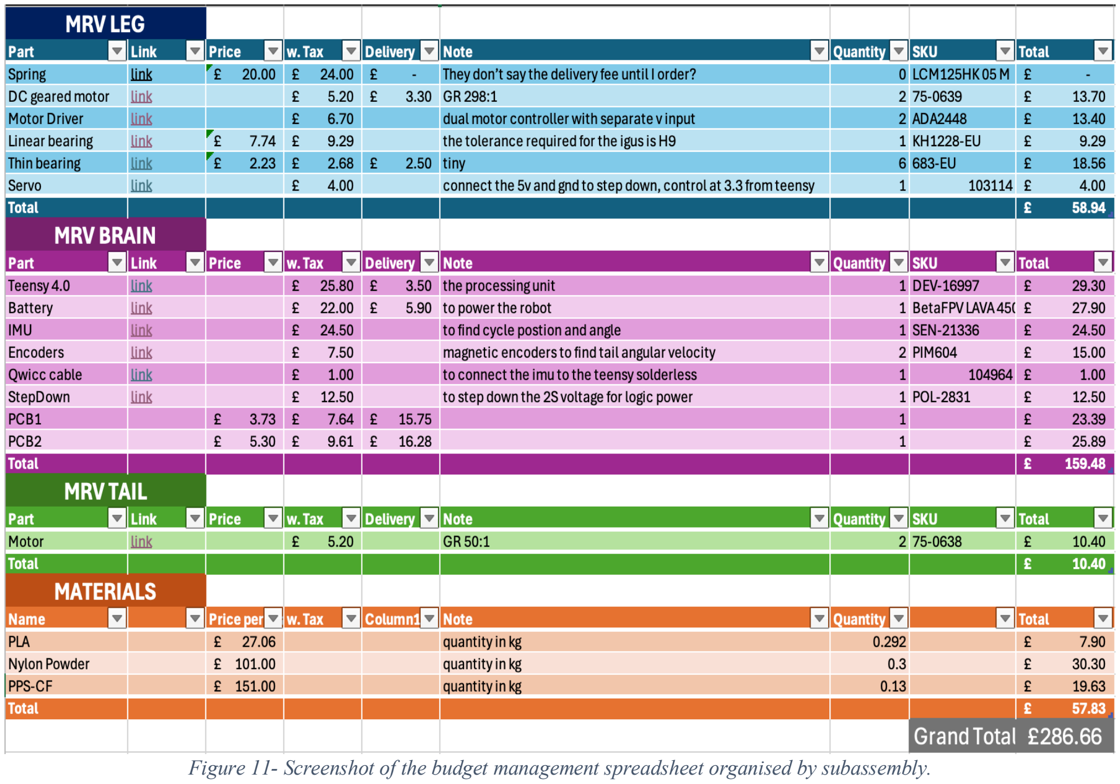
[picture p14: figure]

27

including the reorder). Managing these in parallel was essential to maintain the critical path, particularly when the PCB fault required a second order while other subsystems continued development.

Budget constraints influenced component selection throughout. For example, off-the-shelf geared DC motors were chosen over custom brushless alternatives, and PCB headers were soldered by hand rather than purchasing the surface mounting service. The £13.34 remaining was retained as contingency for replacement components during testing, such as conrods or wedges that cost negligible material.

## 7. Ethical Awareness

Ethics and ethical principles for engineering professionals is a set of required behaviours and practices that guides engineering decision making and taking responsibility for impacts on people, society and environment. These were influential throughout the MRV project by aligning processes, discussions and analyses with ethical guidelines of prioritising safety of the public, such as in the Engineering Build Space (EBS), and rigour in design decision and reporting. Guidelines associated with the location of processes are strictly followed with supervision from competent project supervisor through the weekly project meetings and daily interaction. All source code and CAD files are to be open sourced under the MIT license to enable replication and further development.

Figure 11- Screenshot of the budget management spreadsheet organised by subassembly.

28

### 7.1 Safety hazards and mitigations

Primary safety concerns of the project are related to unexpected and uncontrolled energy release from either the spring or the battery. In the final design of the robot, with the truncated spring, a full compression of 11 cm stores approximately 2.14 J of elastic potential energy, held in place by 3D printed nylon gears. This imposes a projectile risk if the leg extends without an immediate stopping mechanism. Launching the leg assembly in a potential direction of a user of the EBS breaches 05, 06 and 07 of the Core Rules of the EBS [44] and chapter 2 of the Ethical Principles by the Royal Academy of Engineering
[45] hence was mitigated.

As a direct mitigation feature of such risks the final MRV prototype includes the stopper as part of the leg, reducing failure points associated with mitigation strategies. The foot of the leg is detachable and experiences up to 35 N of tension while the gears are closed and the robot is storing potential energy. The risk of a foot projectile is mitigated by screwing down the foot into a threaded insert heat pressed into the core of the leg, well within the FLM printing lowest pull-out force of 1500 N [46].

The reaction wheel counterweights pose a projectile risk if detached during attitude correction. Lead-free pewter was selected partly for its high density, allowing the required moment of inertia to be achieved at lower angular velocities, reducing kinetic energy. Each mass is secured with a safety bolt through the arm mechanically preventing displacement.

LiHV cells are used as the power source of the MRV. Puncturing or short circuiting them poses a fire risk during testing. To mitigate this, a proper battery harness has been manufactured with no exposed conductors. Moreover, the battery is securely attached to the side of the robot and wires do not pass near moving parts preventing entanglement.

Pinch points near the gear mechanisms cause a risk to finger or loose hair in attempts to manipulate the robot during winding. Main drive and motor gear boxes must not be powered when handling the robot and loose hair securely tied back. PPE such as gloves is strongly recommended.

A software safety system detects attitude exceeding 45° and disables motors independently of the main control loop via a 1 kHz interrupt service routine. This prevents uncontrolled arm acceleration while the robot is lying flat preventing breakages resulting in projectile or electrical hazard. PPE such as goggles must be worn.

### 7.2 Responsible testing

Testing was conducted in the EBS under supervision with appropriate PPE including safety glasses. The robot was operated wirelessly on battery power to eliminate cable entanglement near the mechanism. Jump tests used a cable capture system held by an assistant to prevent uncontrolled ground impact. The

29

software safety system can be manually re-enabled only via a serial command, ensuring the operator consciously resumes operation. Stabilisation tests are completed using robust axial bearings and desk clamps to ensure the rig doesn’t tip over with the robot. Trials are to be limited to 5 minutes maximum to avoid the onset of IMU drift jeopardising stabilisation effectiveness. For drop tests, batteries were removed and replaced with equivalent mass to prevent impact damage to live cells.

### 7.3 Sustainability and disposal

Sustainability and disposal have been considered in the design, manufacture and sourcing of components. For example, all PLA parts were optimised to use as little to no supports, minimising waste. SLS nylon powder used as support material is partially reusable or recycled by the manufacturer. Lead-free pewter was used in compliance with safety and environmental standards. LiHV batteries are to be disposed or recycled through university battery recycling [47]. PCB was manufactured by JLCPCB in compliance with RoHS 2.0 standards [48]. Structural components such as the crown use standardised mounting holes, allowing individual parts to be replaced without reprinting the full assembly.

## 8. Conclusions and recommendations for further work

### 8.1 Conclusions

1. A monopedal jumping robot with dual-axis inertial actuators and ratcheted energy recovery was designed, manufactured and tested.
2. The robot achieved a mean jump height of 41.1 cm with a theoretical maximum of 60.6 cm, corresponding to a release efficiency of 67.8%.
3. The high reliability ratcheting mechanism recovered 26% of landing energy at jump-representative heights, with efficiency increasing to 41% at higher impact velocities.
4. Maximum recovery angle of 12.7° was demonstrated on a single axis using bang-bang control, representing the hardware upper bound. At 50% leg extension it increases to an estimated 25.4°.
5. Jump reliability of 57% was traced to cam asymmetry in the release mechanism and leg bending, identified as the priority improvement.
6. The 32° launch tilt from asymmetric release exceeds the ground recovery angle but is theoretically correctable within the 0.58 second flight window, motivating development of state estimation for use in the gain scheduled controller.

### 8.2 What this investigation shows

This investigation demonstrates that controllable, repeatable monopedal hopping stabilised by dual-axis inertial actuators is achievable, with identified paths to improved reliability and energy sustainability. The project validates the integration of elastic energy storage, ratcheted recovery and reaction wheel

30

stabilisation on a single platform, a combination not found in existing literature. The identified failure modes are mechanical in nature and addressable through iterative refinement rather than fundamental redesign, indicating that the concept is sound. The primary outcome of this project is the prototype itself and the demonstration that dual-axis inertially stabilised monopedal hopping is feasible. Performance metrics serve to characterise the first prototype and identify improvement paths, not to optimise a final design.

### 8.3 Further work

All files are to be open sourced under the MIT license for replication. The author recommends the following list of significant suggested further work ranked for anyone continuing the MRV project:

1. Leg linear encoder implementation. A key finding of this project is the necessity of precise leg extension knowledge for gain-scheduled control. This makes the key bearing, preventing the leg rotation about vertical axis, essential for this paradigm to prevent encoder misalignment.
2. LQR controller experimentation. With the implementation of the leg encoder, precise knowledge of the CoM is at hand and can be implemented in the model-based controller. To complete this point, one must also conduct work with parameter identification making it a significant undertaking and representing a scope beyond the 24-week project timeline. Within this, complete PID tuning for continuous stabilisation, using the bang-bang recovery angles as performance targets.
3. Translational locomotion and path planning. This is perhaps the most challenging undertaking suitable for PhD research of a time and financial scale similar to SALTO, requiring years of mechanical perfection and control development.
4. Parallel axis dual inertial actuators for stabilisation. Instead of orthogonal axis, another possible stabilisation method would be to place the axis parallel. This would remove the geometric constraint on reaction wheel radius imposed by orthogonal arm clearance, potentially reducing total robot mass. Yaw control of the robot would be an additional feature that could be used for camera panning. The author suggests this project for anyone interested in characterising a completely new method of inverted pendulum stabilisation perhaps as a research paper similar to the ones in the literature review.
5. FE and impact analysis. Structural simulation of landing loads on the designed structure. This would produce significant material savings throughout the structure through topology optimisation.
6. Environmental hardening. As the aim of the MRV is to explore celestial bodies such as the moon, protection against radiation, thermal cycling and dust sealing must be completed. This is ranked lowest due to being the final step of MRV development.

a
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

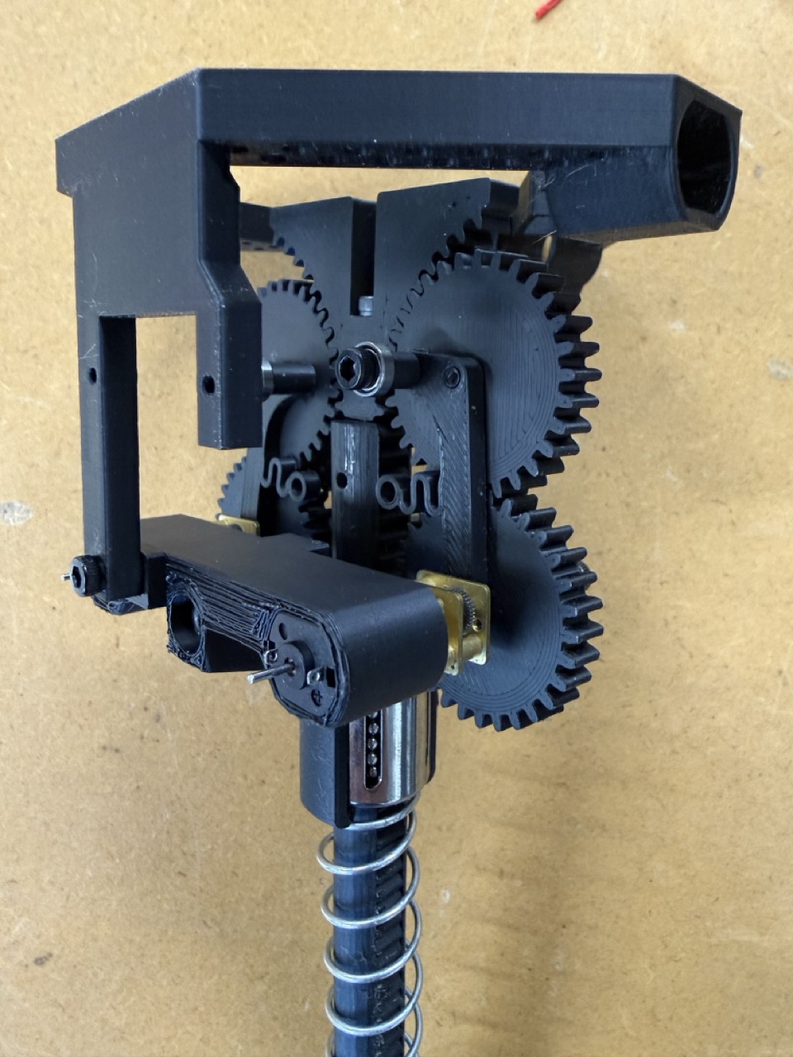
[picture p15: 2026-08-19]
docs/photos/MRV15.jpeg

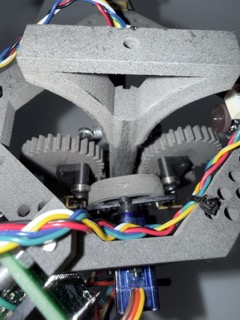
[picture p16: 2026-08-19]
docs/photos/MRV53.jpeg

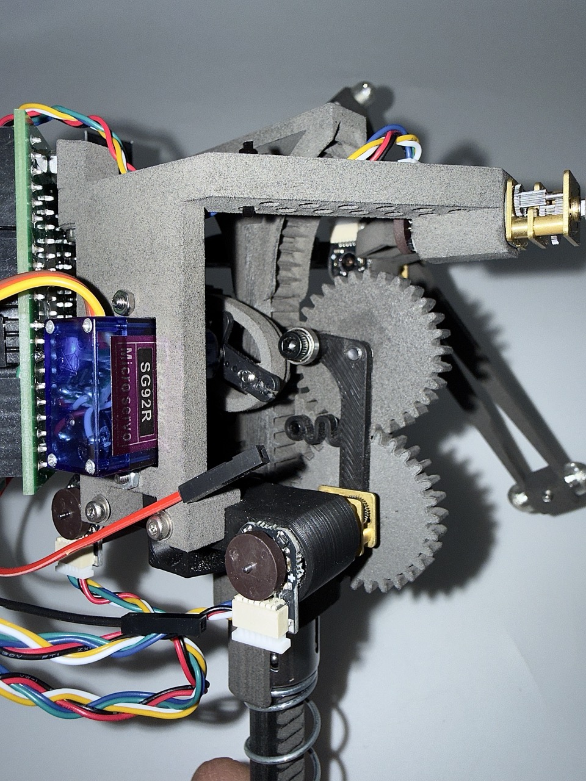
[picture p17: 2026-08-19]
docs/photos/MRV49.jpeg

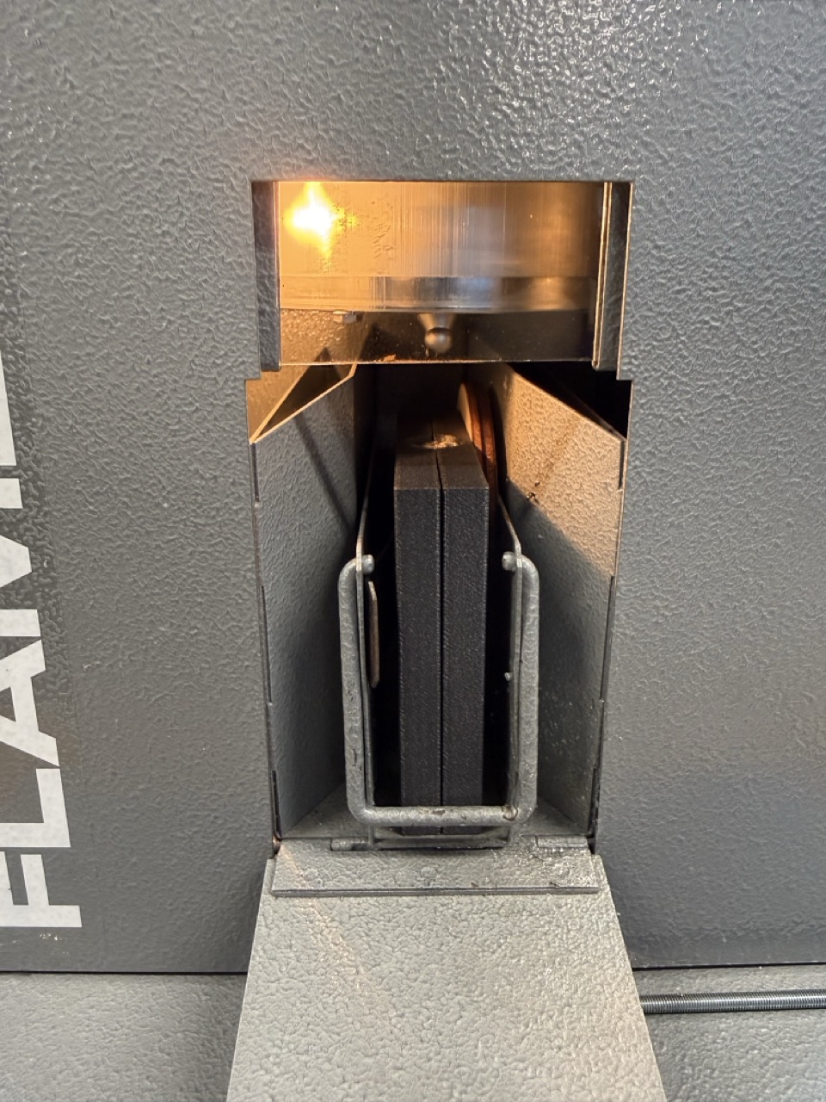
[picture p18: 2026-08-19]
docs/photos/MRV9.jpeg

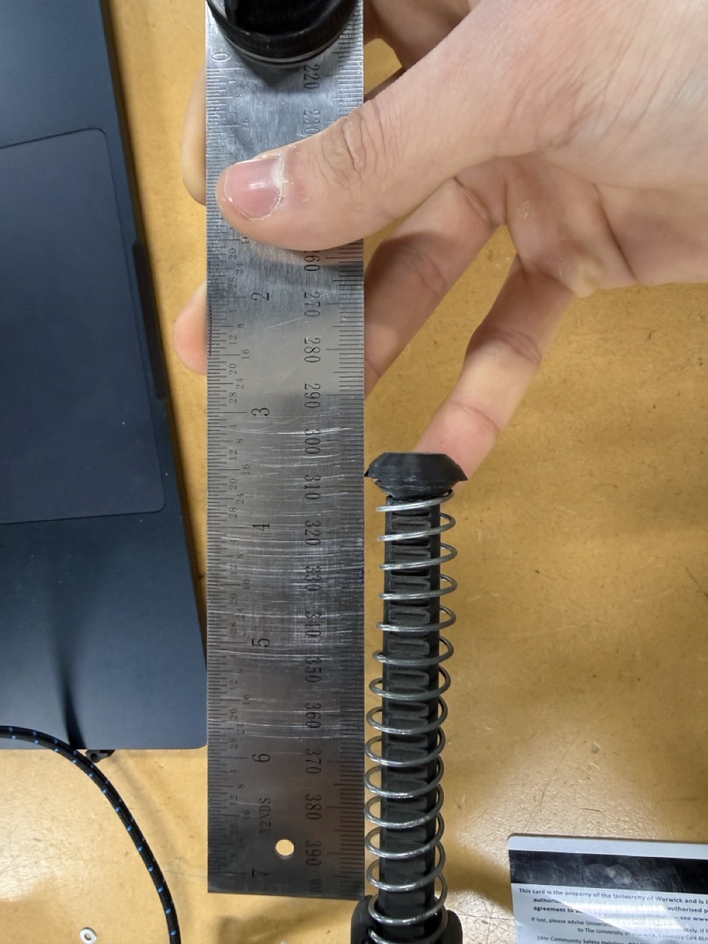
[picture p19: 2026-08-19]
docs/photos/MRV65.jpeg

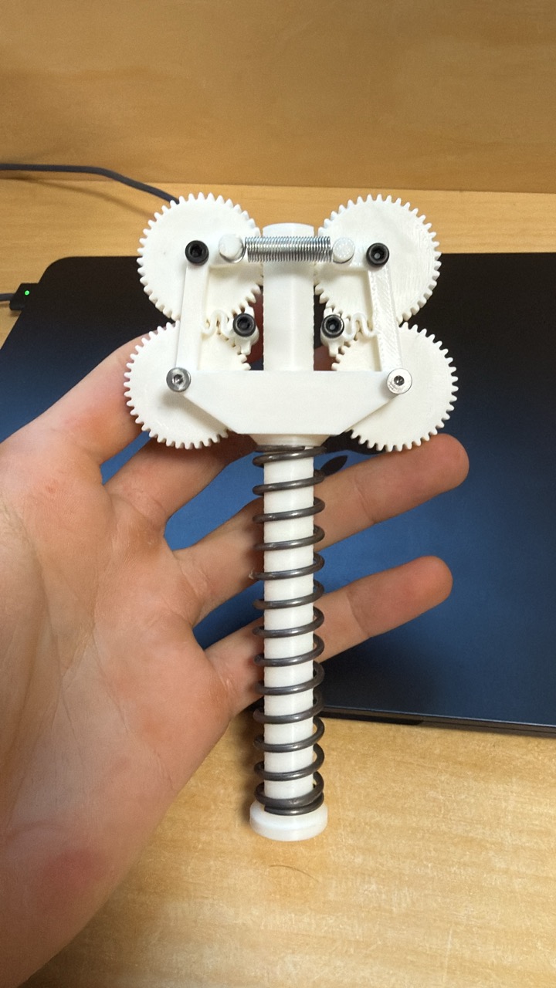
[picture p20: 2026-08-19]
docs/photos/MRV3.jpeg

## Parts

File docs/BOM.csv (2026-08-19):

MRV LEG
Part | Link | Price | w. Tax | Delivery | Weight (g) | Note | Quantity | SKU | Total
Spring | link | £20.00 | £24.00 | £- | 10 | They don’t say the delivery fee until I order? | 0 | LCM125HK 05 M | £- | got a free sample don’t order
DC geared motor | link |  | £5.20 | £3.30 | 22 | GR 298:1 | 2 | 75-0639 | £13.70
Motor Driver | link |  | £6.70 |  | 1.8 | dual motor controller with separate v input | 2 | ADA2448 | £13.40 | Total LeeSpring: £24
Linear bearing | link | £7.74 | £9.29 |  | 18.5 | the tolerance required for the igus is H9 | 1 | KH1228-EU | £9.29 | Total SimplyBearings: £28.34
Thin bearing | link | £2.23 | £2.68 | £2.50 | 12 | tiny | 6 | 683-EU | £18.56 | Total HobbyRc: 27.85
Servo | link |  | £4.00 |  | 9 | connect the 5v and gnd to step down, control at 3.3 from teensy | 1 | 103114 | £4.00 | Total Rapid: £24.74
Total |  |  |  |  | 73.3 |  |  |  | £58.94 | Total PiHut: £103.9
MRV BRAIN
Part | Link | Price | w. Tax | Delivery | Weight (g) | Note | Quantity | SKU | Total
Teensy 4.0 | link |  | £25.80 | £3.50 | 2.8 | the processing unit | 1 | DEV-16997 | £29.30 | Masses: |  | Volumes mm^3:
Battery | link |  | £22.00 | £5.90 | 12.2 | to power the robot | 1 | BetaFPV LAVA 450mAh 1S 75C LiHV Batteries (4pcs) (BT2.0) | £27.90 | total mass: | 155 | Crown: | 23381.936
IMU | link |  | £24.50 |  | 2 | to find cycle postion and angle | 1 | SEN-21336 | £24.50 | top bit mass: | 125 | Gearx4: | 14475.304
Encoders | link |  | £7.50 |  | 3 | magnetic encoders to find tail angular velocity | 2 | PIM604 | £15.00 | leg mass: | 30 | ConrodwSpringx2: | 2335.124
Qwicc cable | link |  | £1.00 |  | 2 | to connect the imu to the teensy solderless | 1 | 104964 | £1.00 | Printed parts top: | 96.5 | Conrodx2: | 1474.34 | Upper Density (g/mm^3): | 0.001674572
StepDown | link |  | £12.50 |  | 1 | to step down the 2S voltage for logic power | 1 | POL-2831 | £12.50 |  |  | MotorMount: | 7365.703 | Leg Density (g/mm^3): | 0.001199397
PCB1 |  | £3.73 | £7.64 | £15.75 |  |  | 1 |  | £23.39 |  |  | Struct: | 8594.273 | Upper Density (g/cm^3): | 1.67457157
PCB2 |  | £5.30 | £9.61 | £16.28 |  |  | 1 |  | £25.89 |  |  | Total Upper: | 57626.68 | Leg Density (g/cm^3): | 1.199396608
Total |  |  |  |  | 23 |  |  |  | £159.48 |  |  | Rack: | 16327.168
MRV TAIL |  |  |  |  |  |  |  |  |  |  |  | Sideleg: | 5194.201
Part | Link | Price | w. Tax | Delivery | Weight (g) | Note | Quantity | SKU | Total |  |  | Stopper: | 3491.208
Motor | link |  | £5.20 |  | 25 | GR 50:1 | 2 | 75-0638 | £10.40 |  |  | Total Lower: | 25012.577
Total |  |  |  |  | 25 |  |  |  | £10.40
MATERIALS
Name |  | Price per quantity | w. Tax | Column1 | 121.3g | Note | Quantity |  | Total
PLA |  | £27.06 |  |  |  | quantity in kg | 0.292 |  | £7.90
Nylon Powder |  | £101.00 |  |  |  | quantity in kg | 0.3 |  | £30.30
PPS-CF |  | £151.00 |  |  |  | quantity in kg | 0.13 |  | £19.63
Total |  |  |  |  |  |  |  |  | £57.83
 |  |  |  |  |  |  |  | Grand Total: | £286.66
PART | Exported?
ARMx2 | TRUE
BallforBearing | TRUE
Cam | TRUE
Clamp | TRUE
ConRodL | TRUE
ConRodR | TRUE
ConwSpringL | TRUE
ConwSpringR | TRUE
Crown | TRUE
DriveNGearx2 | TRUE
DriveRGearx2 | TRUE
Foot | TRUE
Leg | TRUE
Mold | TRUE
MoldSticks | TRUE
MotorMount | TRUE
Sideleg | TRUE
Stopper | TRUE
Struct | TRUE
SymmetricRachet | TRUE
TestRig | TRUE
UnSym Rachet | TRUE
Ball | TRUE

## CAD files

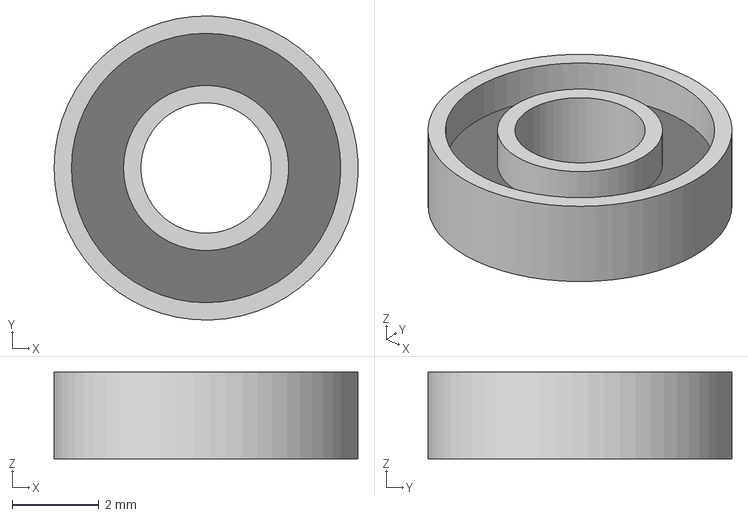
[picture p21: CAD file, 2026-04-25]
Fusion/thinBearing.stp
7.00 x 7.00 x 2.00 mm

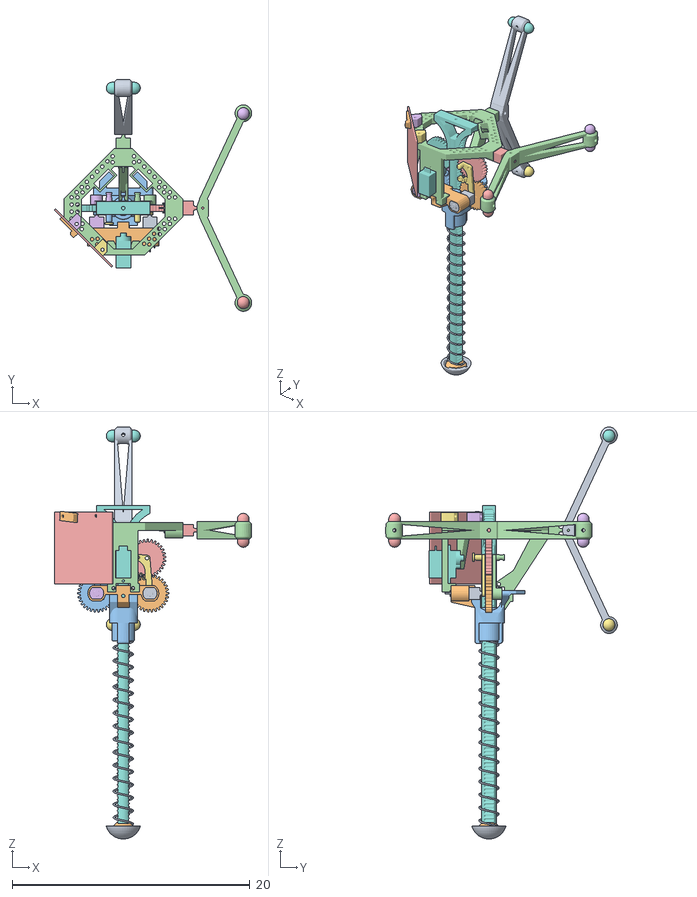
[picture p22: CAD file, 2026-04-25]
models/model.obj
16.6 x 19.5 x 34.6
ThinBearing
DriverGear (1)
DriverGear (1) (1)
ARM
WEIGHT
WEIGHT2
WEIGHT2 (1)
WEIGHT (2)
ARM (1)
Foot
ConRod L
ConRodwSpring R
DrivenGear
ConRodwSpring L
ConRod R
DrivenGear (1)
BALL (1)
DriveMotorMount
Struct
CROWN
PCB
PCB_Mount
PCB_Mount2
LEG

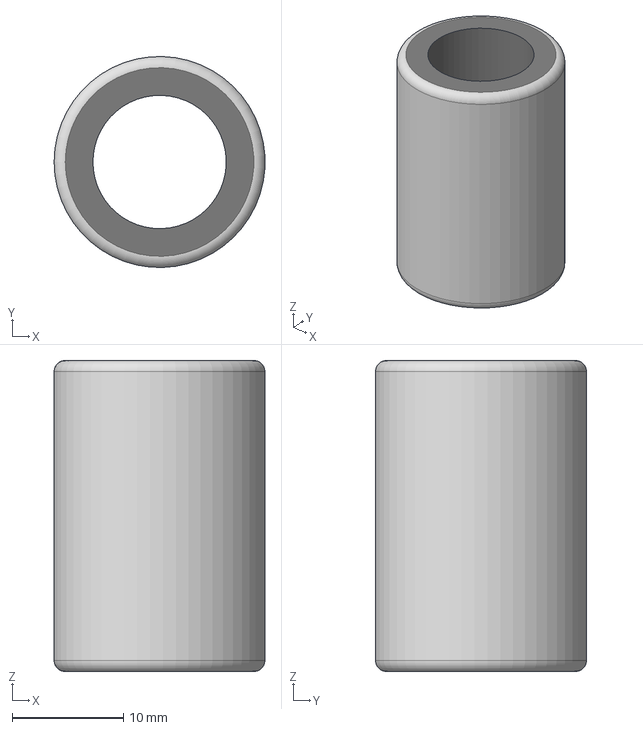
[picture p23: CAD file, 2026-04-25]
Fusion/linear+bearing.stp
19.0 x 19.0 x 28.0 mm

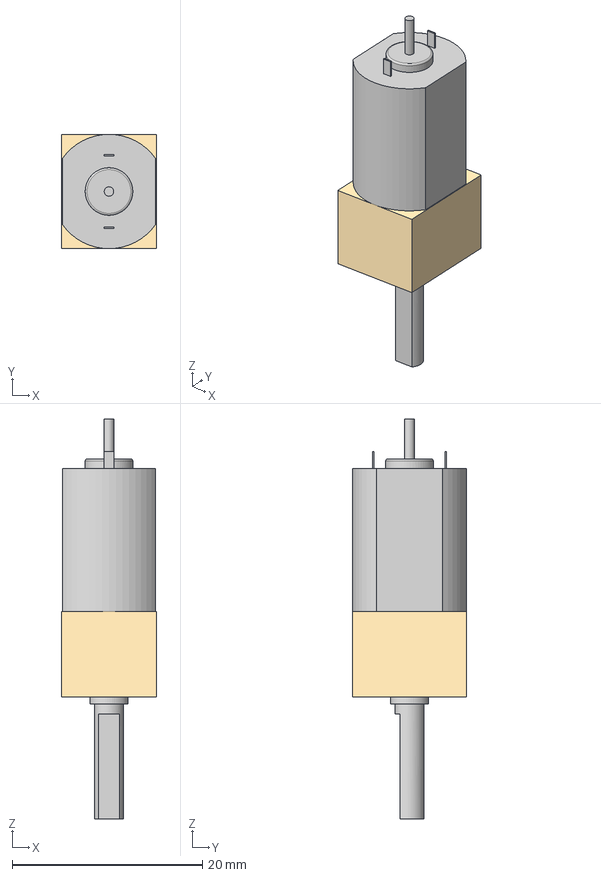
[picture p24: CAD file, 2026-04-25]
Fusion/DC+motor.stp
10.0 x 12.0 x 42.0 mm

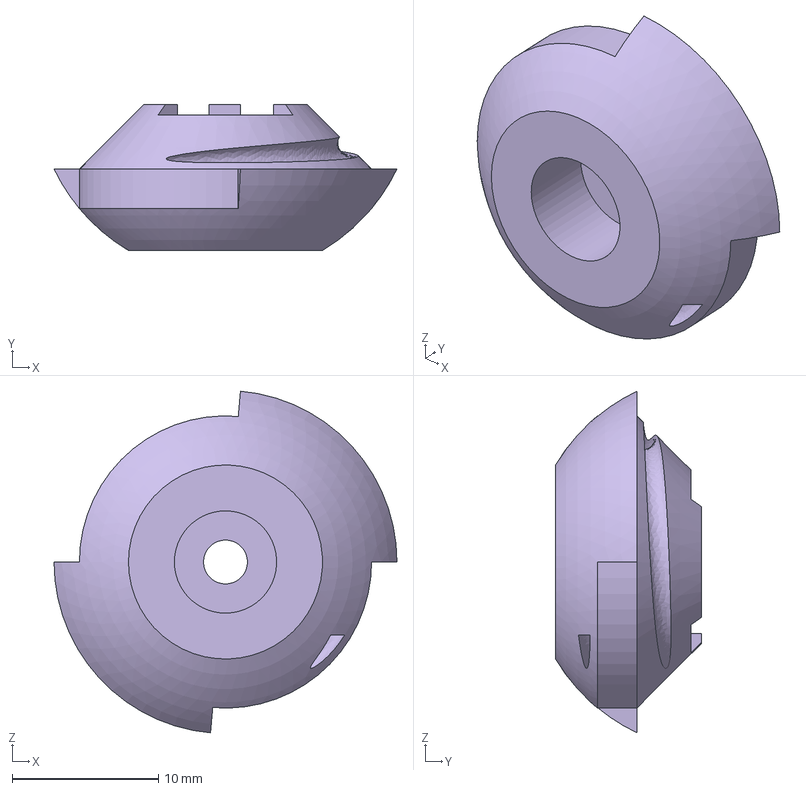
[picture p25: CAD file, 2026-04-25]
Fusion/LArge+feet.stp
23.5 x 10.0 x 23.4 mm

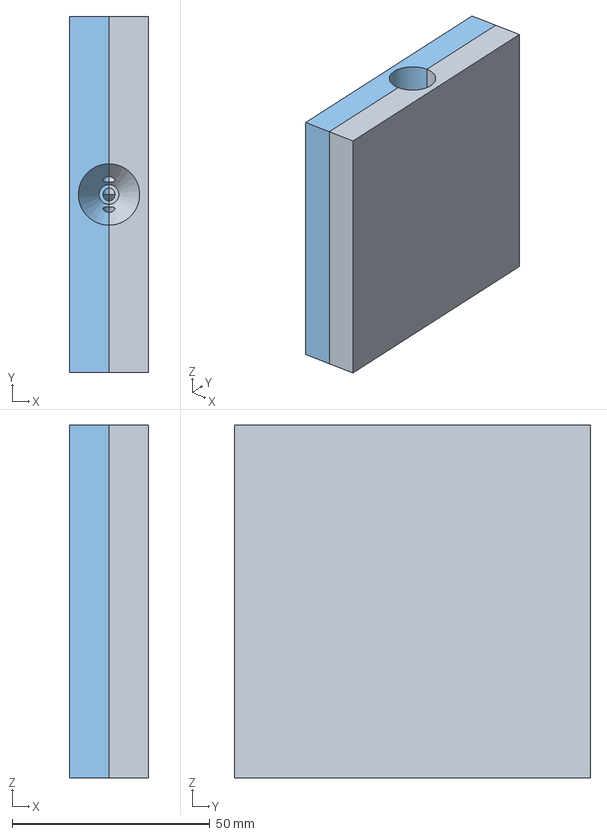
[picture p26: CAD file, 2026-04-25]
Fusion/Weight_Mold.stp
20.0 x 90.0 x 89.2 mm

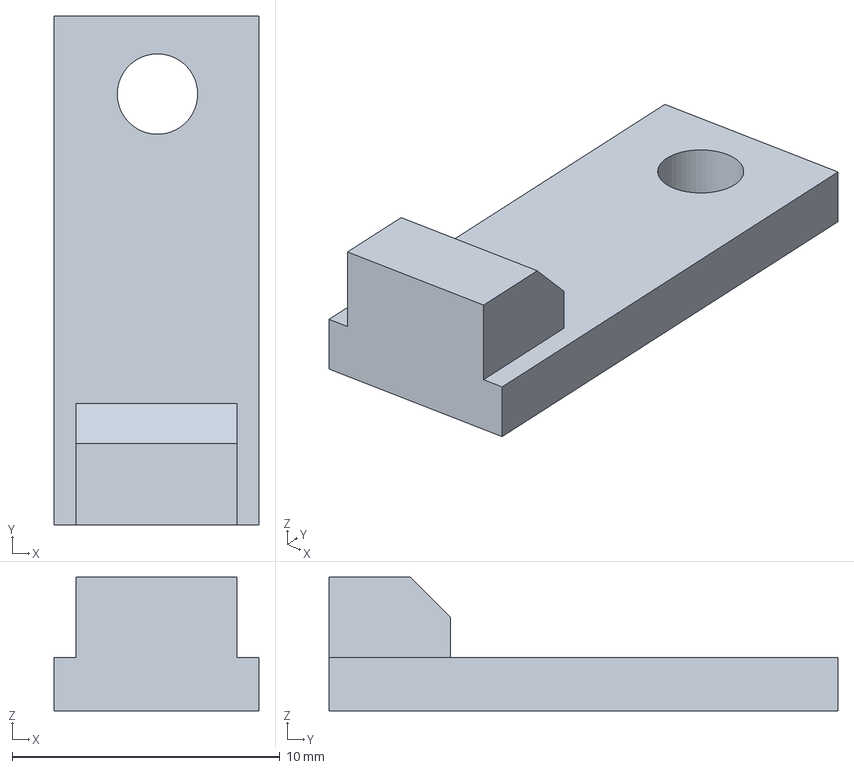
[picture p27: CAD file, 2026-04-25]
Fusion/IMU.stp
7.65 x 19.0 x 5.00 mm

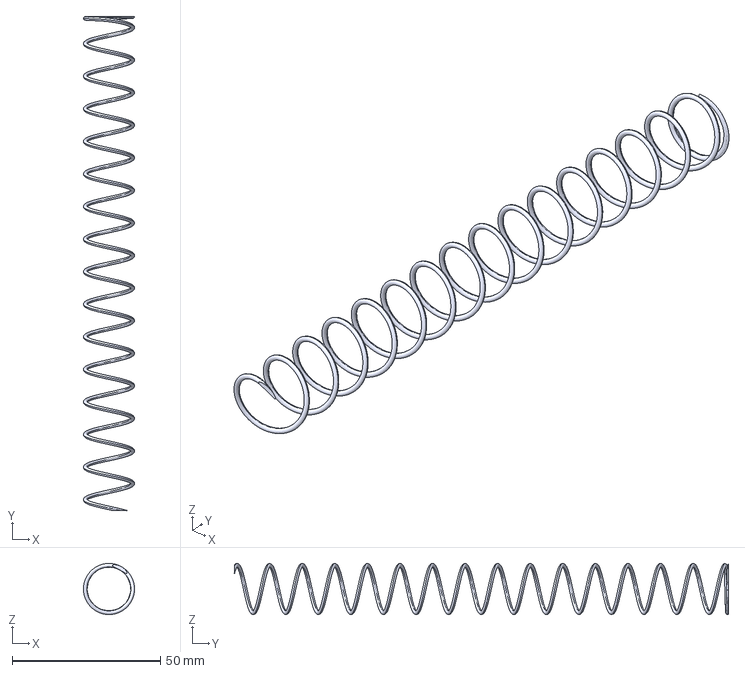
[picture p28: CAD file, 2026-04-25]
Fusion/Spring.stp
17.2 x 166.5 x 17.2 mm

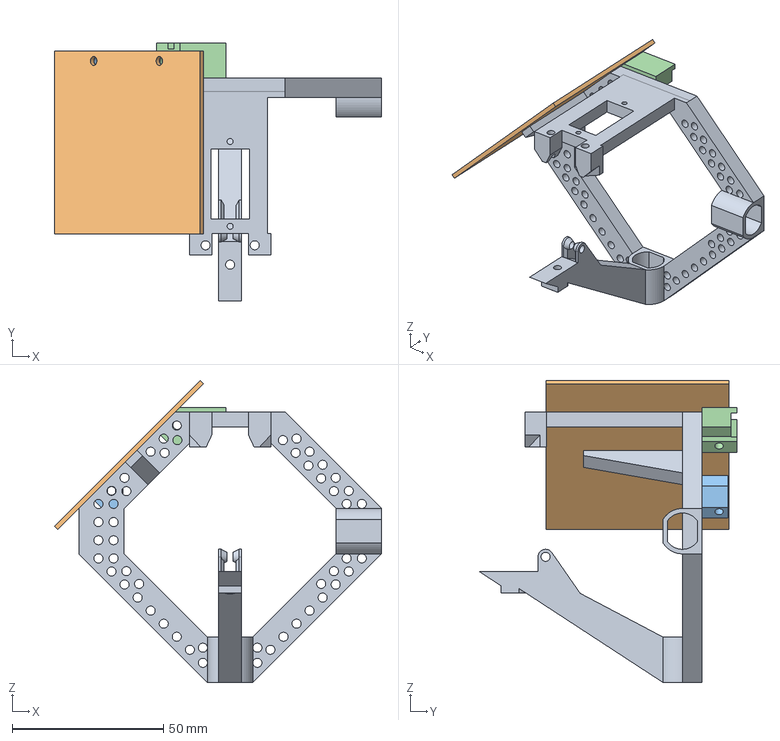
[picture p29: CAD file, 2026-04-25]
Fusion/IMUmount.stp
108.0 x 85.4 x 99.8 mm

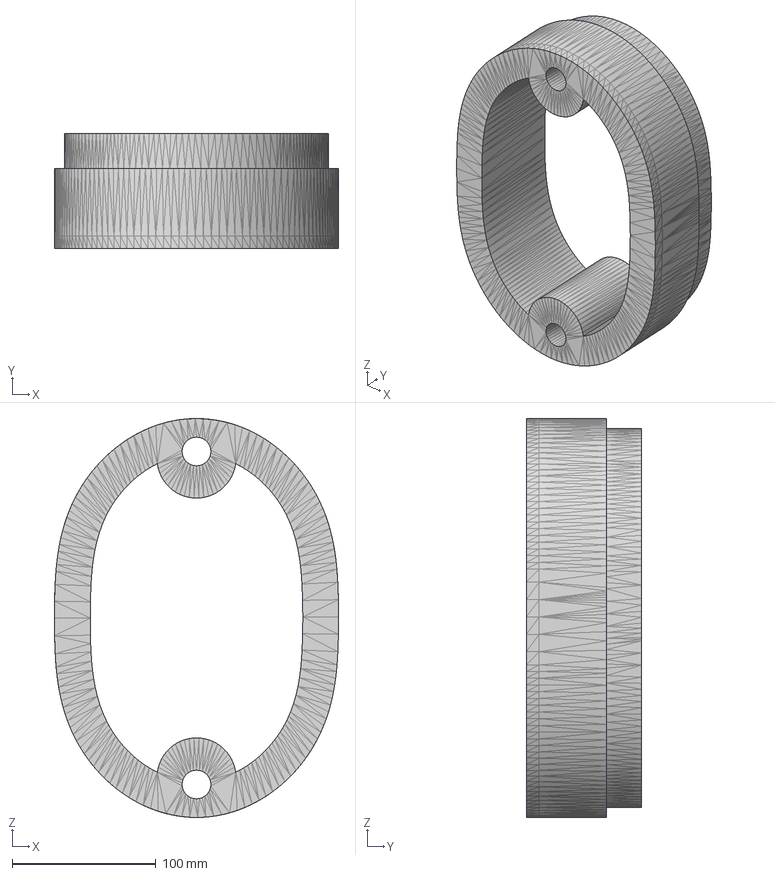
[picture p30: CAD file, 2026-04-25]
Fusion/CAM.stp
198.0 x 80.4 x 278.0 mm

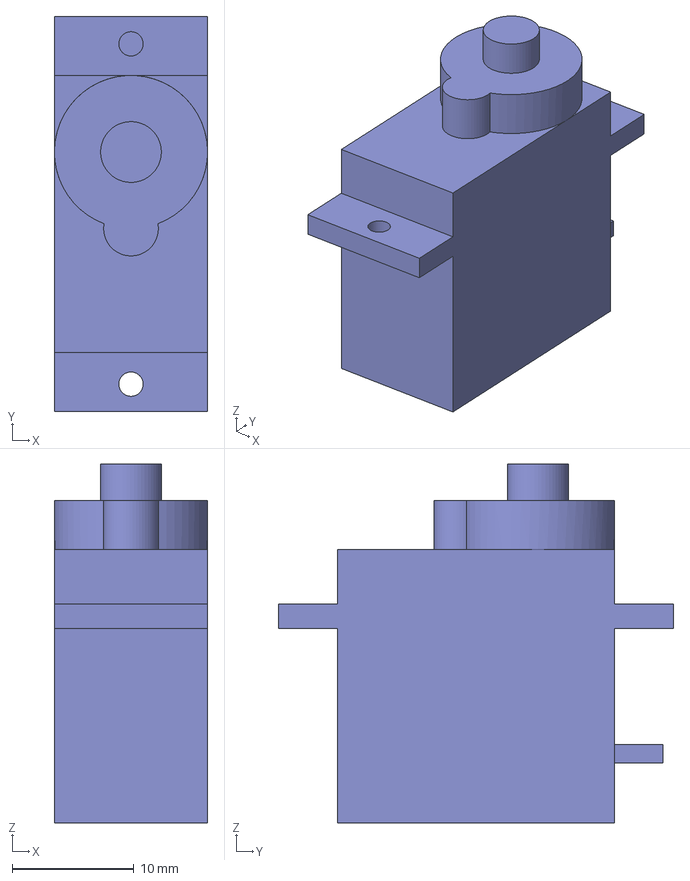
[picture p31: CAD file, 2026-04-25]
Fusion/Servo.stp
12.6 x 32.5 x 29.5 mm

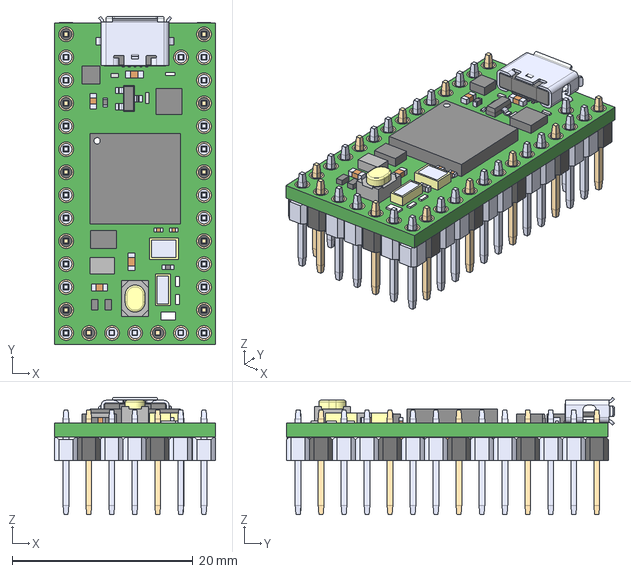
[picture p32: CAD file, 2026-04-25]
Fusion/Teensy40+with+headers.stp
17.8 x 36.3 x 12.9 mm

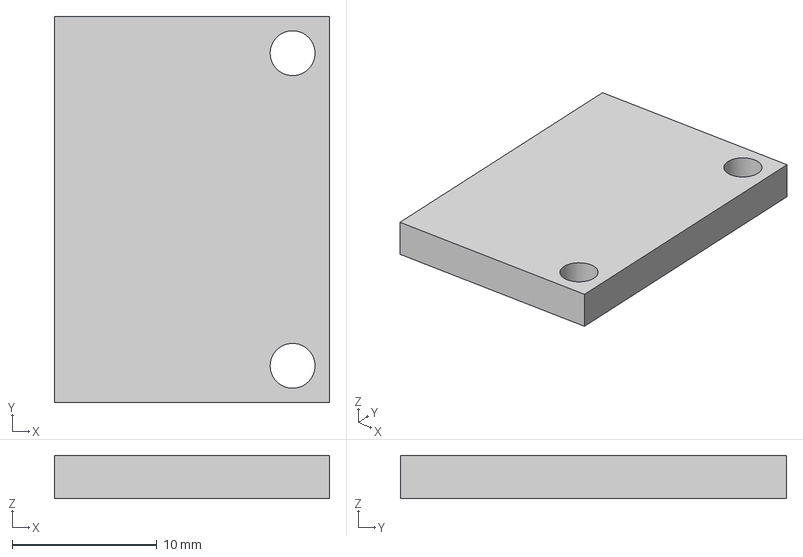
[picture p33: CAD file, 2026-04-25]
Fusion/Motor+driver.stp
19.0 x 26.7 x 3.00 mm

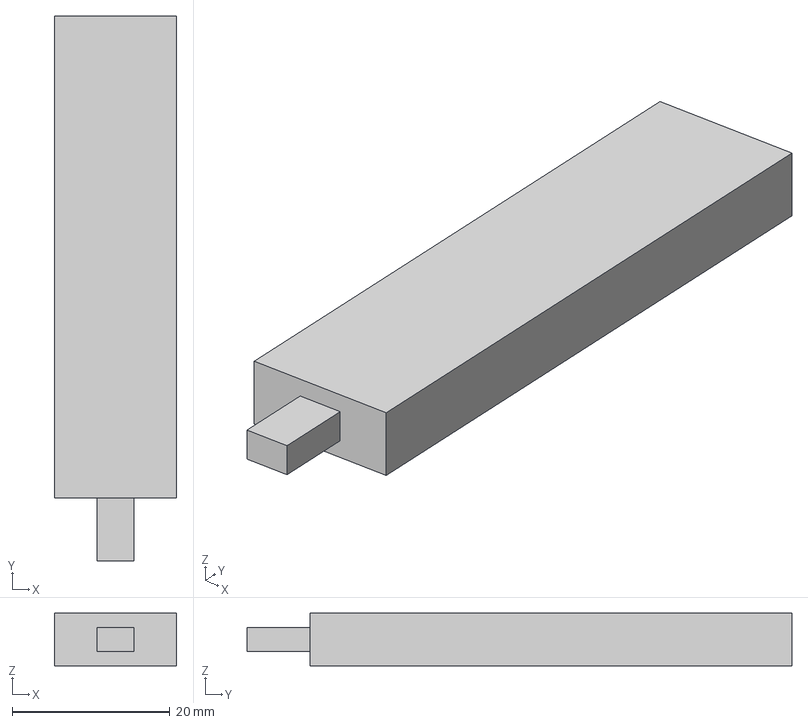
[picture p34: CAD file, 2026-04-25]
Fusion/Battery.stp
15.5 x 69.0 x 6.70 mm

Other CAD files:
Fusion/horn+mounting+sketch.stp
Fusion/PCB.stp

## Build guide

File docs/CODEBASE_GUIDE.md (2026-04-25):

# MRV Robot Controller — Full Codebase Guide

This document explains every file, concept, and decision in the MRV firmware from the ground up. It is written for someone who understands basic programming but may be new to embedded systems, robotics maths, or C++.

---

## Table of Contents

1. [What this project does](#1-what-this-project-does)
2. [Hardware overview](#2-hardware-overview)
3. [Project structure](#3-project-structure)
4. [The build system — PlatformIO](#4-the-build-system--platformio)
5. [Terminology and shorthands](#5-terminology-and-shorthands)
6. [File-by-file walkthrough](#6-file-by-file-walkthrough)
   - [config/config.h](#configconfigh)
   - [hardware/pinout.h](#hardwarepinouth)
   - [hardware/imu.h and imu.cpp](#hardwareimuhandimucpp)
   - [hardware/encoder.h and encoder.cpp](#hardwareencoderhandencordercpp)
   - [hardware/motor_driver.h and motor_driver.cpp](#hardwaremotor_driverhandmotor_drivercpp)
   - [math/quaternion.h and quaternion.cpp](#mathquaternionhandquaternioncpp)
   - [math/filters.h and filters.cpp](#mathfiltershandfilterscpp)
   - [state/robot_state.h and robot_state.cpp](#staterobot_statehrobot_statecpp)
   - [state/state_estimator.h and state_estimator.cpp](#statestate_estimatorhstate_estimatorcpp)
   - [comms/serial_reporter.h and serial_reporter.cpp](#commsserial_reporterhserial_reportercpp)
   - [main.cpp](#maincpp)
7. [Visualisation tools](#7-visualisation-tools)
   - [tools/visualise_imu.py](#toolsvisualise_imupy)
   - [tools/visualise_imu.html](#toolsvisualise_imuhtml)
8. [Data flow — end to end](#8-data-flow--end-to-end)
9. [Serial output format](#9-serial-output-format)
10. [What is stubbed / not yet built](#10-what-is-stubbed--not-yet-built)
11. [Libraries reference](#11-libraries-reference)

---

## 1. What this project does

The MRV robot has a physical body with moving arms and joints. This firmware runs on a small computer (a **Teensy 4.0** microcontroller) that is mounted on the robot. Its current jobs are:

1. Read the **IMU** (inertial measurement unit) 120 times per second to find out how the robot body is oriented in space — is it tilted? Rotated? Upright?
2. Express that orientation as a **quaternion** (a compact mathematical description of rotation — explained below).
3. Derive human-readable **roll, pitch, and yaw** angles from the quaternion using standard ZYX Euler conversion.
4. Read the **ARM0** (pins 22/23) and **ARM1** (pins 20/21) **joint encoders** and convert quadrature counts to degrees, angular velocity (deg/s), and angular acceleration (deg/s²).
5. Read two **speed encoders** (pins 14/15 and 16/17) and report shaft RPM.
6. Drive **arm motors** (TB6612FNG H-bridge, pins 8/9/10/11/12) and a **spring motor** (pins 2/7) via serial commands from the visualiser.
7. Run a **safety cutoff ISR** at 1 kHz that kills all motors if roll or yaw exceeds 45° — independent of the main loop.
8. Send all sensor data over **USB serial** to a connected computer 10 times per second.
9. Accept incoming serial commands (`ARM:`, `SPR:`, `SAFE_CLR`) from the visualiser to control motors.
10. Display the live orientation and arm angles in a **3D visualiser** (either Python or web browser).

Remaining future work: wire the LEG encoder (joint index 2).

---

## 2. Hardware overview

| Component | Part | Role |
|---|---|---|
| Microcontroller | **Teensy 4.0** | Runs the firmware. ARM Cortex-M7 CPU at 600 MHz. |
| IMU | **LSM6DSV16X** | 6-axis IMU (accelerometer + gyroscope). Has a built-in fusion processor. |
| IMU breakout | SparkFun Micro 6DoF (Qwiic) | Breakout board for the LSM6DSV16X, communicates via I²C. |
| ARM0 encoder | PIM604 quadrature encoder on pins 22/23 | Measures the angle of the left arm joint in degrees. |
| ARM1 encoder | PIM604 quadrature encoder on pins 20/21 | Measures the angle of the right arm joint in degrees. |
| Speed encoders | PIM604 on pins 14/15 and 16/17 | Measure shaft RPM for two drive motors. |
| Arm motor driver | **TB6612FNG** dual H-bridge | Drives two arm motors (A and B) via pins 8/9/10/11/12. STBY on pin 10 = safety cutoff. |
| Spring motor driver | **TB6612FNG** (channels paralleled) | Drives the spring winding motor via pins 2/7. STBY permanently HIGH. |
| LEG encoder | Not yet wired (joint index 2) | Will measure vertical slide position. |

**IMU** stands for *Inertial Measurement Unit*. It measures two things:
- **Accelerometer**: linear acceleration in three axes (X, Y, Z). At rest it measures gravity.
- **Gyroscope**: angular velocity (rotation speed) in three axes.

The LSM6DSV16X combines both measurements inside the chip using a **SFLP** (Sensor Fusion Low Power) engine to produce a smooth orientation estimate, output as a quaternion.

---

## 3. Project structure

```
MRV_code/
│
├── platformio.ini          ← Build configuration (compiler, libraries, ports)
│
├── models/
│   └── model.obj           ← 3D model of the robot (used only by the visualiser)
│
├── src/                    ← All firmware source code
│   ├── main.cpp            ← Entry point (setup + loop)
│   │
│   ├── config/
│   │   └── config.h        ← Every tunable constant in one place
│   │
│   ├── hardware/
│   │   ├── pinout.h           ← Every pin number in one place
│   │   ├── imu.h/.cpp         ← IMU driver (fully implemented)
│   │   ├── encoder.h/.cpp     ← Joint encoder driver (ARM0+ARM1 active, speed encoders, kinematics)
│   │   └── motor_driver.h/.cpp ← TB6612 H-bridge driver with safety cutoff
│   │
│   ├── math/
│   │   ├── quaternion.h/.cpp ← Quaternion maths
│   │   └── filters.h/.cpp    ← Signal filters (stub — not yet needed)
│   │
│   ├── state/
│   │   ├── robot_state.h/.cpp       ← The data structure holding current robot state
│   │   └── state_estimator.h/.cpp   ← Runs the sampling loop, populates state
│   │
│   └── comms/
│       └── serial_reporter.h/.cpp   ← Sends state to the computer over USB
│
└── tools/                  ← PC-side tools (not part of the firmware)
    ├── visualise_imu.py    ← Python 3D visualiser
    └── visualise_imu.html  ← Web browser 3D visualiser (uses WebSerial + Three.js)
```

**Key rule: one responsibility per file.** Every file has exactly one job. The IMU file knows nothing about serial output. The serial file knows nothing about quaternion maths. This makes each file easier to understand, test, and replace.

---

## 4. The build system — PlatformIO

### What is a build system?

A build system automates the process of turning your source code (`.cpp`, `.h` files) into a binary that can run on the Teensy. It handles:
- Compiling each source file
- Linking them together
- Downloading the result to the device

### PlatformIO

PlatformIO is a build system and package manager for embedded projects. It is an extension for VS Code. The configuration lives in **`platformio.ini`**.

### `platformio.ini` explained

```ini
[env:teensy40]
platform       = teensy          ← Use the Teensy compiler toolchain
board          = teensy40        ← Specific board: Teensy 4.0
framework      = arduino         ← Use the Arduino API (setup/loop, Serial, etc.)

lib_deps =
    stm32duino/STM32duino LSM6DSV16X  ← Auto-download the IMU library
    paulstoffregen/Encoder            ← Auto-download the quadrature encoder library

build_flags =
    -std=gnu++17   ← Use C++17 standard (more modern C++ features)
    -I src         ← Add src/ to the include search path
    -Wall          ← Enable common compiler warnings
    -Wextra        ← Enable extra compiler warnings

upload_protocol = teensy-cli             ← Use teensy-cli tool to upload
upload_port     = /dev/cu.usbmodem...    ← The USB port the Teensy is connected to
monitor_speed   = 115200                 ← Baud rate for the serial monitor
```

**Baud rate**: the speed of serial communication, in bits per second. Both sides (Teensy and computer) must agree on the same number. 115200 is a common fast rate.

**`-I src`**: This tells the compiler that when code writes `#include "config/config.h"`, it should look in the `src/` directory first. Without this flag, the path would need to be written differently.

---

## 5. Terminology and shorthands

### C++ basics

| Term | Meaning |
|---|---|
| `#pragma once` | Tells the compiler to include this header file at most once per compilation unit. Prevents duplicate definitions. |
| `#include "file.h"` | Paste the contents of `file.h` here at compile time. Quotes = local project file. |
| `#include <library.h>` | Same but angle-brackets = system or external library. |
| `constexpr` | A constant whose value is known at compile time. Computed once; zero runtime cost. Safer than `#define`. |
| `static` (inside a file) | The variable or function is only visible in this file. Other files cannot accidentally use it. |
| `volatile` | Tells the compiler this variable can change at any time (e.g., from an interrupt), so it must never cache it in a register. |
| `uint8_t`, `uint16_t`, `uint32_t` | Unsigned integers of exactly 8, 16, or 32 bits. The `u` suffix on a number literal (e.g., `120u`) makes it unsigned. |
| `float` | 32-bit floating-point number. Used for all sensor maths. |
| `const` | A value that cannot be changed after it is set. |
| `static constexpr` | A compile-time constant that belongs to a class but is shared across all instances (not per-object). |
| `F("string")` | Arduino macro. Stores the string in flash memory instead of RAM. Important on chips with limited RAM (less relevant on Teensy 4.0 but good practice). |

### C++ concepts

| Term | Meaning |
|---|---|
| **Header file** (`.h`) | Declares *what* exists: class names, function signatures, constants. Shared between files. |
| **Source file** (`.cpp`) | Defines *how* it works: the actual function bodies. |
| **Class** | A blueprint for an object. Bundles data (fields) and behaviour (methods) together. |
| **Constructor** | A special method called automatically when an object is created. Sets initial values. |
| **`begin()`** | A common pattern in Arduino code: initialise hardware once in `setup()`. |
| **`update()`** / **`tick()`** | Methods called repeatedly in `loop()` to do ongoing work. |
| **`private`** | Fields or methods only accessible from inside the class. |
| **`public`** | Fields or methods accessible from outside the class. |
| **`const` method** | A method that promises not to modify the object. Written as `void foo() const;`. |
| **Reference** (`&`) | An alias for another variable. Avoids copying large objects. `const Quaternion& q` means "a reference to a Quaternion I promise not to modify." |
| **`explicit` constructor** | Prevents accidental automatic conversions. E.g., `explicit IMU()` means you must write `IMU()` explicitly and the compiler won't silently convert other types to an IMU. |
| **ISR** | Interrupt Service Routine. A function that runs automatically when a hardware event fires (e.g., a timer). Must be very fast and avoid slow operations like I²C. |
| **Heap** | Dynamic memory allocated with `new`/`malloc`. Fragmentation is dangerous on embedded systems. This project avoids the heap. |
| **Stack** | Automatic memory for local variables in a function. Cleaned up when the function returns. |

### Embedded / hardware terms

| Term | Meaning |
|---|---|
| **I²C** (I2C / IIC) | Inter-Integrated Circuit. A two-wire bus (SDA + SCL) for communicating with sensors at low speed. This project uses I²C for the IMU. |
| **SPI** | Serial Peripheral Interface. A four-wire bus, faster than I²C. The IMU can optionally use SPI (not the default in this project). |
| **FIFO** | First-In, First-Out buffer. The IMU stores new quaternion samples in a FIFO queue on-chip. The firmware reads and drains it. |
| **ODR** | Output Data Rate. How many times per second the sensor produces a new reading. |
| **FS / FSR** | Full-Scale Range. The maximum value the sensor can measure. ±2g for the accelerometer means it saturates at twice Earth's gravity. ±250 dps for the gyroscope means it saturates at 250 degrees per second. Smaller range = finer resolution. |
| **IntervalTimer** | A Teensy hardware timer that calls a function at a precise interval. Teensy 4.0 has four of them. |
| **micros()** | Arduino function. Returns the number of microseconds since the program started (as a 32-bit unsigned integer, wraps after ~70 minutes). |
| **millis()** | Same but in milliseconds. |
| **Baud rate** | Serial communication speed in bits per second. |
| **WHO_AM_I** | A standard register on I²C/SPI sensors that returns the chip's ID. Used to verify the sensor is connected and responding correctly. |
| **SA0** | A hardware pin on the LSM6DSV16X that selects one of two I²C addresses. Tied HIGH on the SparkFun board → address 0x6B. |
| **Quadrature encoder** | A rotary position sensor with two output signals (A and B) that are 90° out of phase. The phase difference reveals direction; counting transitions reveals position. |
| **PPR** | Pulses Per Revolution. The number of complete A/B cycles an encoder produces per shaft revolution. In full quadrature (4× counting), 1 PPR = 4 raw counts. |
| **CPR / counts per rev** | Total quadrature counts per revolution = 4 × PPR. This is the number you configure in `ENC_ARM1_COUNTS_PER_REV`. |
| **Gear ratio** | How many encoder shaft turns per one joint output turn. If the encoder is geared 5:1 down to the arm, one full arm rotation = 5 encoder revolutions. |

### Sensor fusion terms

| Term | Meaning |
|---|---|
| **SFLP** | Sensor Fusion Low Power. ST's proprietary algorithm running inside the LSM6DSV16X chip, combining accelerometer and gyroscope data to produce a stable orientation estimate. |
| **Game rotation vector** | The specific SFLP output used here: a quaternion representing 3-DOF orientation (no magnetometer). Yaw is relative to power-on, not magnetic north. |
| **Quaternion** | A 4-number representation of a 3D rotation. More compact and numerically stable than Euler angles. Described in detail below. |
| **Euler angles** | Roll, pitch, yaw — three angles describing rotation about three axes. Intuitive but suffer from gimbal lock. |
| **Roll** | Rotation about the front-to-back (X) axis. Like tilting your head to the side. |
| **Pitch** | Rotation about the left-to-right (Y) axis. Like nodding. |
| **Yaw** | Rotation about the vertical (Z) axis. Like shaking your head "no". |
| **Gimbal lock** | A situation where two rotation axes align, causing the loss of one degree of freedom. Occurs when pitch reaches ±90°. Quaternions avoid this. |
| **Drift** | Slow accumulation of error in the yaw angle over time, because the SFLP engine has no magnetometer to give an absolute yaw reference. Roll and pitch drift very little because gravity provides an absolute reference. |

### Three.js / visualiser terms

| Term | Meaning |
|---|---|
| **Three.js** | A JavaScript library that makes 3D graphics in a web browser easy. Wraps the browser's WebGL API. |
| **WebGL** | The browser's 3D graphics API, based on OpenGL. Three.js sits on top of it. |
| **WebSerial** | A browser API (Chrome and Edge only) that allows a web page to talk directly to a USB serial port. |
| **OBJ / MTL** | Common 3D model file formats. `.obj` stores geometry (vertices, faces). `.mtl` stores materials (colours, textures). |
| **Slerp** | Spherical Linear Interpolation. Smoothly interpolates between two quaternion orientations. Used to add visual damping so the 3D model doesn't jitter. |
| **AxesHelper** | A Three.js object that draws three coloured arrows: Red = X, Green = Y, Blue = Z. |
| **OrbitControls** | A Three.js add-on that lets you drag to rotate the camera, scroll to zoom, and right-drag to pan. |
| **Pivot** | The point about which the 3D model rotates. Set to the bottom of the robot's foot so the robot appears to stand on the ground. |
| **Z-up vs Y-up** | Three.js uses Y as the "up" axis. Autodesk (which exported the OBJ) uses Z as "up". A 90° rotation corrects this. |
| **Conjugation** (quaternion) | R·q·R⁻¹ — a way to change a quaternion's reference frame. Used to apply the IMU's axis corrections without breaking continuous rotation. |
| **IMU_OFFSET_INV** | A correction quaternion that cancels the 45° angle at which the IMU board is physically mounted on the robot. |

---

## 6. File-by-file walkthrough

---

### `config/config.h`

**Purpose:** Single source of truth for every number in the project. No magic numbers appear anywhere else.

**Why this matters:** If you want to change the sample rate, you change it in one place. Every file that needs it just reads this header.

```cpp
constexpr uint16_t IMU_SAMPLE_RATE_HZ = 120u;
```
The firmware asks the IMU for a new orientation reading 120 times per second. This matches the IMU chip's maximum fusion rate (SFLP_ODR_HZ).

```cpp
constexpr uint16_t SERIAL_REPORT_RATE_HZ = 10u;
```
The firmware only prints to the serial port 10 times per second. Reading 120 Hz and printing 10 Hz avoids flooding the USB connection while still getting smooth sensor data internally.

```cpp
constexpr float IMU_ACCEL_ODR_HZ = 120.0f;
constexpr uint8_t  IMU_ACCEL_FS_G  = 2u;
```
The accelerometer is configured to measure 120 times per second, with a ±2g full-scale range. ±2g means if the robot accelerates faster than twice Earth's gravity (unlikely), readings will saturate. The smaller the range, the more detail you get within it.

```cpp
constexpr float    IMU_GYRO_ODR_HZ  = 120.0f;
constexpr uint16_t IMU_GYRO_FS_DPS  = 250u;
```
The gyroscope: 120 Hz, ±250 degrees per second. The robot moves slowly, so this range gives good resolution.

```cpp
constexpr float SFLP_ODR_HZ      = 120.0f;
constexpr uint8_t SFLP_ENABLE_GBIAS = 1u;
```
The SFLP fusion engine runs at 120 Hz. `GBIAS` (gyroscope bias estimation) is enabled — the chip tracks slow drift in the gyroscope and corrects for it automatically over ~30 seconds of use.

```cpp
constexpr uint16_t IMU_FIFO_WATERMARK = 1u;
```
The IMU's internal FIFO buffer. A watermark of 1 means: as soon as one sample is ready, the firmware reads it. Keeps latency minimal.

```cpp
constexpr float ENC_ARM1_COUNTS_PER_REV = 12.0f;  // DO NOT TOUCH
constexpr float ENC_ARM1_GEAR_RATIO     = 50.0f;  // DO NOT TOUCH
```
ARM1 encoder calibration for the **Pimoroni PIM604** Rotary Encoder Breakout. Empirically calibrated — the effective counts-per-rev is 12 (not the nominal 96) due to the encoder's output characteristics. The ARM1 joint has a **50:1 gear reduction** between the encoder shaft and the arm output. ARM0 uses identical constants (`ENC_ARM0_COUNTS_PER_REV = 12.0f`, `ENC_ARM0_GEAR_RATIO = 50.0f`).

```cpp
constexpr float ENC_ARM0_INIT_DEG = 0.0f;
constexpr float ENC_ARM1_INIT_DEG = 90.0f;
```
Calibration offsets: the physical rest position in degrees at power-on. ARM1 starts at 90° because of its mounting orientation.

```cpp
constexpr uint8_t NUM_SPEED_ENCODERS = 2u;
constexpr float ENC_SPEED_COUNTS_PER_REV = 96.0f;
```
Two speed-only encoders (pins 14/15 and 16/17) report shaft RPM but not absolute position.

```cpp
constexpr uint8_t ENC_VEL_WINDOW = 10u;
constexpr float   ENC_VEL_ALPHA  = 0.10f;
```
Encoder kinematics filter: velocity is computed over a sliding window of 10 ticks (~83 ms at 120 Hz). An EMA filter with alpha=0.10 smooths the velocity before acceleration is derived.

```cpp
constexpr float ACCEL_TILT_ALPHA = 0.15f;
```
EMA smoothing factor for raw accelerometer tilt computation (reserved for future use — currently not called in the main path).

```cpp
constexpr uint32_t SAFETY_CHECK_RATE_HZ = 1000u;
constexpr float    SAFETY_TILT_DEG      = 45.0f;
```
The safety ISR runs at 1 kHz in its own IntervalTimer. If |roll| or |yaw| exceeds 45°, the arm motor driver asserts STBY LOW and all motors stop. Motors can only be re-enabled via the `SAFE_CLR` serial command once tilt is back within limits.

```cpp
constexpr uint8_t IMU_I2C_SA0 = 1u;
constexpr uint32_t IMU_I2C_CLOCK_HZ = 400000u;
```
`SA0 = 1` selects I²C address 0x6B (the SparkFun breakout board default). 400,000 Hz = 400 kHz = "Fast Mode" I²C — four times faster than the 100 kHz default.

---

### `hardware/pinout.h`

**Purpose:** Every Teensy pin number in one place. Hardware wiring changes only require editing this file.

```cpp
// IMU
constexpr uint8_t PIN_IMU_INT1   = 2u;   // sensor INT1 (unused — firmware polls)
constexpr uint8_t PIN_IMU_SPI_CS = 10u;  // SPI chip-select (unused — I2C mode)

// Joint encoders
constexpr uint8_t PIN_ENC_ARM0_A = 22u;  // ARM0 (left arm) encoder channel A
constexpr uint8_t PIN_ENC_ARM0_B = 23u;  // ARM0 encoder channel B
constexpr uint8_t PIN_ENC_ARM1_A = 20u;  // ARM1 (right arm) encoder channel A
constexpr uint8_t PIN_ENC_ARM1_B = 21u;  // ARM1 encoder channel B

// Speed encoders
constexpr uint8_t PIN_ENC_SPD2_A = 14u;  // Speed encoder 2 channel A
constexpr uint8_t PIN_ENC_SPD2_B = 15u;  // Speed encoder 2 channel B
constexpr uint8_t PIN_ENC_SPD3_A = 16u;  // Speed encoder 3 channel A
constexpr uint8_t PIN_ENC_SPD3_B = 17u;  // Speed encoder 3 channel B

// Arm motors (TB6612FNG)
constexpr uint8_t PIN_ARM_AIN2 = 8u;   // Motor A direction 2
constexpr uint8_t PIN_ARM_AIN1 = 9u;   // Motor A direction 1 / PWM
constexpr uint8_t PIN_ARM_STBY = 10u;  // Standby — LOW kills both arm motors (safety cutoff)
constexpr uint8_t PIN_ARM_BIN1 = 11u;  // Motor B direction 1 / PWM
constexpr uint8_t PIN_ARM_BIN2 = 12u;  // Motor B direction 2

// Spring motor (TB6612FNG, channels paralleled)
constexpr uint8_t PIN_SPR_IN1 = 7u;   // Spring forward direction / PWM
constexpr uint8_t PIN_SPR_IN2 = 2u;   // Spring reverse direction / PWM

// Status LED
constexpr uint8_t PIN_LED = 13u;
```

**Pin sharing notes:** `PIN_IMU_SPI_CS` (pin 10) and `PIN_ARM_STBY` (pin 10) share the same physical pin — this is safe because SPI mode is disabled (I2C is used). Similarly, `PIN_IMU_INT1` (pin 2) and `PIN_SPR_IN2` (pin 2) share because the INT1 interrupt is unused (firmware polls the IMU).

---

### `hardware/imu.h` and `imu.cpp`

**Purpose:** Talk to the LSM6DSV16X chip and deliver a clean quaternion. Nothing outside this file needs to know how the sensor works.

#### The class interface (`imu.h`)

The `IMU` class has seven public methods:

| Method | When to call | What it does |
|---|---|---|
| `IMU()` | Automatically on creation | Sets quaternion to identity, marks as uninitialised |
| `begin()` | Once in `setup()` | Starts I²C, configures chip, starts FIFO |
| `update()` | Each sample tick | Drains the FIFO, stores the latest quaternion |
| `getQuaternion()` | After `update()` | Returns the stored quaternion |
| `calibrate()` | On demand | Resets the SFLP engine to re-zero orientation |
| `getRawAccel(ax,ay,az)` | On demand | Reads the accelerometer output in g (polled, not FIFO) |
| `getStatusString()` | After any method | Returns a human-readable status/error string |

#### What `begin()` does step by step (`imu.cpp`)

1. **Start the I²C bus** at 400 kHz
2. **WHO_AM_I check** — call `_sensorPtr->begin()`. The library reads the sensor's ID register. If it doesn't match the expected value, the sensor is not connected or is at the wrong address.
3. **Enable the accelerometer** (`Enable_X()`) and set its ODR and full-scale range
4. **Enable the gyroscope** (`Enable_G()`) and set its ODR and full-scale range
5. **Set SFLP ODR** — how fast the fusion engine runs
6. **Enable the rotation vector** — turns on SFLP and tells it to write quaternions to the FIFO
7. **Set FIFO watermark** to 1
8. **Set FIFO mode** to stream (continuous) — when the FIFO is full, oldest samples are overwritten, so you always get the freshest reading

#### What `update()` does

The FIFO may contain several samples if the loop is slightly late. The function reads *all* of them but keeps only the last one:

```
for each sample in FIFO:
    read its tag (what type of data is it?)
    if tag == kTagGameRv (0x13):
        read the quaternion data
        store it (do NOT stop — keep reading to get the freshest)
    else:
        consume the 6 bytes anyway to advance the read pointer
```

The tag `0x13` (`kTagGameRv`) identifies SFLP game rotation vector data. The chip's C header defines this as an anonymous enum value, which is inaccessible from C++ by name, so the raw hex value is used directly.

#### Module-static sensor object

```cpp
static LSM6DSV16XSensor s_sensor(&Wire, LSM6DSV16X_I2C_ADD_H);
```

`static` here means this variable lives only in `imu.cpp` — no other file can see or accidentally modify it. The `IMU` class holds a pointer to it (`_sensorPtr`). This avoids heap allocation while still allowing the class to be used normally.

---

### `hardware/encoder.h` and `encoder.cpp`

**Purpose:** Read quadrature encoders on each robot joint and convert counts to degrees, angular velocity, and angular acceleration. ARM0 (joint index 0, pins 22/23) and ARM1 (joint index 1, pins 20/21) are fully implemented. Two speed-only encoders (pins 14/15 and 16/17) report shaft RPM.

The class is named **`JointEncoders`** (not `Encoder`) to avoid a naming collision with the `Encoder` class from the paulstoffregen library, which is used internally inside `encoder.cpp`.

#### Quadrature encoding

A rotary encoder outputs two square waves called **channel A** and **channel B**. The waves are 90° out of phase with each other. By watching which channel transitions first, you can tell:
- **Direction**: if A rises before B, it's spinning clockwise; if B rises before A, it's counter-clockwise.
- **Position**: each full cycle of the two channels = 4 counts. The PIM604 is a 24 PPR encoder, so it nominally produces 4 × 24 = 96 quadrature counts per encoder shaft revolution.

The paulstoffregen/Encoder library handles all of this using hardware interrupts — the CPU is notified every time a pin changes, counts are kept automatically, and you just call `read()` to get the current count.

#### Counts-to-degrees conversion

```
degrees = count × 360 / (ENC_ARM1_COUNTS_PER_REV × ENC_ARM1_GEAR_RATIO)
```

- `ENC_ARM1_COUNTS_PER_REV` — empirically calibrated to 12.0 (not the nominal 96).
- `ENC_ARM1_GEAR_RATIO` — 50.0 (50:1 gear reduction).
- ARM0 uses identical constants.

#### Kinematics (velocity and acceleration)

Angular velocity is computed over a sliding window of `ENC_VEL_WINDOW` (10) past angle samples — total angle change divided by total elapsed time. This averages away quantisation noise. The velocity is then smoothed with an EMA filter (`ENC_VEL_ALPHA = 0.10`), and acceleration is derived as the rate of change of the smoothed velocity.

#### `begin()`

Resets counts to zero and applies calibration offsets (`ENC_ARM0_INIT_DEG`, `ENC_ARM1_INIT_DEG`) so the power-on position is defined correctly. ARM1 starts at 90° because of its mounting orientation.

#### Joint index mapping

| Index | Joint | Status |
|---|---|---|
| 0 | ARM (left) | **active — pins 22/23** |
| 1 | ARM(1) (right) | **active — pins 20/21** |
| 2 | LEG (vertical slide) | stub — 0° (not yet wired) |

#### Speed encoders

Two additional PIM604 encoders (96 CPR) on pins 14/15 and 16/17 report shaft RPM only — no position tracking. RPM is computed from count differences between successive `update()` calls.

---

### `hardware/motor_driver.h` and `motor_driver.cpp`

**Purpose:** Controls two TB6612FNG dual H-bridge breakout boards for arm and spring motors, with a hardware safety cutoff.

#### Two motor boards

| Board | Motors | STBY | Control pins |
|---|---|---|---|
| Arm board | Motor A (pins 9/8) + Motor B (pins 11/12) | Pin 10 (software-controlled) | Sign-magnitude PWM on IN pins |
| Spring board | Channels A+B paralleled (pins 7/2) | Permanently HIGH (3.3V) | Same PWM scheme |

#### Speed control

Uses sign-magnitude PWM with PWMA/PWMB assumed tied HIGH:
- **Forward**: `analogWrite(IN1, duty)`, `digitalWrite(IN2, LOW)`
- **Reverse**: `digitalWrite(IN1, LOW)`, `analogWrite(IN2, duty)`
- **Coast**: both LOW

#### Safety cutoff

`safetyStop()` is called from the safety ISR (interrupt context) when tilt exceeds the threshold. It:
1. Asserts `PIN_ARM_STBY` LOW — instantly kills both arm motors at the hardware level
2. Coasts the spring motor (both IN pins LOW)
3. Latches the `_safetyTripped` flag (volatile, ISR-safe)

All subsequent `setArmA()`, `setArmB()`, `setSpring()` calls are silently ignored while the latch is set. `clearSafety()` re-enables the driver (STBY HIGH) and clears the latch, but motor outputs remain at zero until the next explicit command.

---

### `math/quaternion.h` and `quaternion.cpp`

**Purpose:** All quaternion mathematics. No hardware or Arduino dependencies — pure maths.

#### What is a quaternion?

A quaternion is a way to represent a 3D rotation using four numbers: `(x, y, z, w)`.

- `w` is the **scalar** part. For a rotation of angle θ around an axis, `w = cos(θ/2)`.
- `x, y, z` are the **vector** part. They encode the axis of rotation, scaled by `sin(θ/2)`.
- A **unit quaternion** (one where x²+y²+z²+w²=1) always represents a valid pure rotation.

Why use quaternions instead of roll/pitch/yaw?
- They avoid **gimbal lock** (when pitch reaches ±90°, yaw and roll collapse into the same thing)
- They are compact (4 numbers vs. a 3×3 rotation matrix's 9 numbers)
- They compose (multiply) smoothly and numerically stably
- They interpolate naturally via **slerp**

The identity quaternion `(0, 0, 0, 1)` means "no rotation" — the object is in its reference orientation.

#### Key operations

**Normalize:**
```
|q|² = x²+y²+z²+w²
q_normalised = q / sqrt(|q|²)
```
Keeps the quaternion on the unit sphere after floating-point arithmetic may have drifted it slightly off.

**Conjugate:**
```
q* = (-x, -y, -z, w)
```
For a unit quaternion, the conjugate is the inverse (undoes the rotation).

**Hamilton product (multiplication):**
Quaternion multiplication is not commutative: `p×q ≠ q×p`. It composes two rotations: "first rotate by q, then rotate by p" = `p×q`.

**ZYX Euler conversion:**
The firmware converts quaternions to roll/pitch/yaw for human-readable output. The ZYX convention means: first yaw (rotate around Z), then pitch (around Y), then roll (around X). This is the standard robotics convention.

The maths uses `atan2f`, `asinf` — the `f` suffix means single-precision float, using the Teensy's hardware floating-point unit (FPU) for speed.

**Gimbal lock handling:** When `|sinp| >= 1` (pitch is exactly ±90°), `asinf` would produce `NaN`. The code clamps `sinp` to [-1, 1] before calling `asinf`, returning ±90° safely.

---

### `math/filters.h` and `filters.cpp`

**Purpose:** Placeholder for software signal filters (e.g., Kalman, complementary, low-pass).

Currently empty stubs. Because the LSM6DSV16X SFLP engine does its own high-quality sensor fusion in hardware, software filters are not needed for orientation. This module exists for future use if, for example, encoder readings need filtering.

---

### `state/robot_state.h` and `robot_state.cpp`

**Purpose:** The central data structure that holds a complete snapshot of the robot's state at one instant in time.

```cpp
struct RobotState {
    Quaternion imuQuaternion;                     // SFLP orientation (x, y, z, w)
    float roll, pitch, yaw;                       // ZYX Euler angles in degrees
    float jointAngles[NUM_ENCODER_JOINTS];        // [0]=ARM0, [1]=ARM1, [2]=LEG
    float jointAngularVelDps[NUM_ENCODER_JOINTS]; // deg/s per joint
    float jointAngularAccDps2[NUM_ENCODER_JOINTS];// deg/s² per joint
    float encoderSpeedRPM[NUM_SPEED_ENCODERS];    // [0]=pins 14/15, [1]=pins 16/17
    uint32_t timestampUs;                         // when this snapshot was taken
};
```

This is a **plain data struct** — it has no logic, no hardware access, just data. Think of it as a form that gets filled in by `StateEstimator` and read by `SerialReporter` and the safety ISR.

Methods:
- `reset()` — sets all fields back to zero / identity defaults
- `copyFrom(src)` — copies all fields from another `RobotState`
- `print()` — prints a debug summary to Serial (for development use)

---

### `state/state_estimator.h` and `state_estimator.cpp`

**Purpose:** Runs the sampling loop. Decides *when* to read the IMU, calls it, and populates `RobotState`.

#### The IntervalTimer pattern

The Teensy 4.0 has four hardware **IntervalTimers**. A timer fires a callback function at a precise interval regardless of what the main loop is doing.

However: the callback runs in **interrupt context** — it interrupts whatever the CPU was doing. I²C (the bus used to talk to the IMU) cannot safely be used from inside an interrupt, because the I²C library uses internal state that could be partially modified when interrupted.

The solution is a two-stage pattern:

```
Timer fires every 1/120th second
  → ISR: _samplePending = true     ← ONLY this, very fast

Main loop runs continuously
  → tick(): if _samplePending:
       _samplePending = false
       read IMU over I²C             ← safe here
       update RobotState
```

The `volatile` keyword on `_samplePending` is essential. Without it, the compiler might optimise away the check (thinking: "nothing in this function changes `_samplePending`, so I'll just cache it as false"). `volatile` forces the compiler to re-read the variable from memory every time.

#### `tick()` step by step

1. If `_samplePending` is false: return immediately (nothing to do)
2. Clear the flag *before* the I²C read (if the I²C takes a long time, a new timer tick might fire — clearing early means that flag is not lost)
3. Call `_encoders.update()` — snapshots the latest quadrature counts for all active joints
4. Copy the resulting angles, velocities, accelerations, and speed RPMs into `_state`
5. Call `_imu.update()` — drains the FIFO, returns true if a quaternion was found
6. If a quaternion was found:
   - Store it in `_state.imuQuaternion`
   - Convert to Euler: `q.toEuler(_state.roll, _state.pitch, _state.yaw)` (standard ZYX)
   - Record the current timestamp: `_state.timestampUs = micros()`
7. If `update()` returns false (FIFO was empty or there was a bus error): leave the quaternion unchanged — consumers always have the last valid reading

Encoders are read on every tick regardless of whether the IMU FIFO had new data, so joint angles and kinematics stay current at 120 Hz.

---

### `comms/serial_reporter.h` and `serial_reporter.cpp`

**Purpose:** Sends the current `RobotState` to the connected computer over USB serial, at a controlled rate.

#### Rate limiting

The firmware samples the IMU at 120 Hz but only needs to print at 10 Hz. Instead of using a second timer, `SerialReporter` checks the elapsed time every time `update()` is called:

```cpp
const uint32_t now = micros();
if ((now - _lastReportUs) < kReportIntervalUs) {
    return;  // too soon — do nothing
}
_lastReportUs = now;
// ... print ...
```

Unsigned subtraction (`now - _lastReportUs`) handles the 70-minute wraparound of `micros()` correctly: if `now` has wrapped around to a small value, the subtraction still gives the correct elapsed time.

`kReportIntervalUs = 1,000,000 / 10 = 100,000 microseconds = 100 ms` between prints.

#### Output format

Each line looks like:
```
T:12345678 | Q:0.01234,0.00123,-0.00456,0.99990 | RPY:2.34,1.23,-0.56 | J:12.3,88.6,0.0 | K:5.40,12.30 | S:120.5,0.0
```

| Field | Meaning |
|---|---|
| `T:<us>` | Teensy timestamp in microseconds |
| `Q:<x>,<y>,<z>,<w>` | IMU quaternion (5 decimal places) |
| `RPY:<r>,<p>,<y>` | Roll, pitch, yaw in degrees (2 decimal places) |
| `J:<j0>,<j1>,<j2>` | Three joint angles in degrees (ARM0, ARM1, LEG) |
| `K:<vel>,<acc>` | ARM1 angular velocity (deg/s) and acceleration (deg/s²) |
| `S:<rpm0>,<rpm1>` | Speed encoder RPMs (pins 14/15 and 16/17) |

The `F("literal")` macro stores string constants in flash memory instead of RAM — a good habit from Arduino days when RAM was scarce.

---

### `main.cpp`

**Purpose:** Entry point. Wires the subsystems together and manages the safety cutoff and serial command parser.

#### Two Arduino functions

Every Arduino/Teensy program has exactly two mandatory functions:
- `setup()` — called once at startup
- `loop()` — called repeatedly forever after

```cpp
// Five global objects, created at program start:
static IMU            imu;
static JointEncoders  encoders;
static StateEstimator stateEstimator(imu, encoders);
static SerialReporter reporter;
static MotorDriver    motors;
```

`static` here means file-scope — these live for the entire program lifetime and are not accessible from other files.

#### Safety ISR

A dedicated IntervalTimer runs `safetyISR()` at 1 kHz — independently of the main loop and I2C traffic. It reads `roll` and `yaw` from `RobotState` and, if either exceeds `SAFETY_TILT_DEG` (45°), calls `motors.safetyStop()` which asserts STBY LOW (arm motors off) and coasts the spring motor. The latched flag blocks all motor commands until `SAFE_CLR` is received over serial.

#### Serial command parser

The firmware accepts newline-terminated commands from the visualiser:

| Command | Action |
|---|---|
| `ARM:<a>,<b>` | Set arm motor A and B speeds (-255 to 255) |
| `SPR:<speed>` | Set spring motor speed (-255 to 255) |
| `SAFE_CLR` | Re-enable motors (only if tilt is back within limits) |

#### `setup()` sequence

1. Configure LED pin as an output, turn it off
2. Open serial at 115200 baud; wait up to 3 seconds for a USB connection
3. `motors.begin()` — configures all motor pins, STBY HIGH, outputs zeroed
4. `encoders.begin()` — resets counts and applies calibration offsets; prints a warning if it fails but does **not** halt
5. `imu.begin()` — if this fails, call `faultHalt()`: blink the LED rapidly and print the error forever
6. `stateEstimator.begin()` — starts the 120 Hz IntervalTimer; if no timer is available, blink at medium speed and halt
7. Start the safety IntervalTimer at 1 kHz
8. Turn LED on solid (= all OK)

#### `faultHalt()`

If a critical initialisation step fails, there is no useful work the firmware can do. `faultHalt()` enters an infinite loop that blinks the LED at the given period. Different blink speeds indicate different faults:
- 200 ms (fast): IMU failure — check wiring and I²C address
- 500 ms (medium): IntervalTimer resource exhausted

#### `loop()`

```cpp
void loop() {
    readSerialCommands();                       // parse motor/safety commands
    stateEstimator.tick();                      // process one IMU sample if ready
    if (s_safetyJustTripped) { ... }            // relay "SAFE:1" to serial
    reporter.update(stateEstimator.getState()); // print if interval elapsed
}
```

The loop runs thousands of times per second. Most `tick()` calls return immediately (no sample pending). Most `reporter.update()` calls return immediately (not yet time to print). This is correct and efficient — the CPU is idle most of the time.

---

## 7. Visualisation tools

These tools run on your computer (not on the Teensy) and read the serial output.

---

### `tools/visualise_imu.py`

**Language:** Python 3
**Libraries:** `pyserial`, `numpy`, `matplotlib`

A quick-start visualiser. Opens the serial port, reads quaternion data, and displays three animated arrows representing the robot's X, Y, Z axes.

#### Running it

```bash
# Activate your Python virtual environment first, then:
pip install pyserial numpy matplotlib
python tools/visualise_imu.py /dev/cu.usbmodem187379501
```

#### How it works

- A **background thread** (`_serial_thread`) reads from the serial port continuously. It parses `Q:x,y,z,w` and `RPY:r,p,y` from each line and writes them into shared variables (`_quat`, `_rpy`) protected by a **threading lock**.
- A **threading lock** (`_lock`) prevents the display thread from reading a quaternion while the serial thread is in the middle of writing it (which would give corrupted half-old, half-new values).
- The **main thread** runs `matplotlib`'s animation loop, which calls `_update()` 20 times per second.
- `_update()` converts the quaternion to a **3×3 rotation matrix** using the Hamilton formula, then redraws three arrows (quivers) along the three columns of that matrix.

#### Quaternion → rotation matrix

```
R = | 1-2(y²+z²)   2(xy-zw)   2(xz+yw) |
    | 2(xy+zw)   1-2(x²+z²)   2(yz-xw) |
    | 2(xz-yw)     2(yz+xw) 1-2(x²+y²) |
```

The columns of R are where the X, Y, Z axes point after the rotation.

---

### `tools/visualise_imu.html`

**Language:** HTML + JavaScript (ES modules)
**Libraries:** Three.js (loaded from CDN), WebSerial API (built into Chrome/Edge)

The main visualiser. Loads the actual 3D robot model and shows it rotating in real time. Also controls arm and spring motors via serial commands and displays RPY calibration offsets, arm encoder angles, and live telemetry graphs.

#### Running it

```bash
# From the project root:
python3 -m http.server 8080
# Then open Chrome or Edge and go to http://localhost:8080/tools/visualise_imu.html
```

A local HTTP server is required because browsers block loading local files for security reasons (CORS policy). The visualiser needs to load `models/model.obj` and `models/model.mtl`.

**WebSerial requires Chrome or Edge.** Safari does not support it.

#### Three.js scene structure

```
Scene
├── GridHelper         ← grey floor grid
├── AmbientLight       ← fills shadows
├── DirectionalLight   ← main sun-like light
├── DirectionalLight   ← fill light (blue tint)
└── pivot (Object3D)   ← quaternion rotation applied here
    ├── AxesHelper     ← Red=X, Green=Y, Blue=Z arrows
    └── wrapper (Group)
        ├── rotation.x = -π/2   ← converts Z-up OBJ to Y-up Three.js
        ├── scale = 20/maxDim   ← normalises model size
        └── obj (the robot model, positioned so foot sits at wrapper origin)
```

The key insight: the pivot's origin is at the foot bottom. When the quaternion rotates the pivot, the whole robot rotates *about its foot*, which is what you see physically.

ARM0 and ARM1 meshes have their own rotation pivots built using `buildArmPivot()`, which creates a parent group centred at the mesh's bounding-box centroid. Arm angles from the `J:` serial field drive `arm0Mesh.rotation.y` and `arm1Mesh.rotation.x` respectively, with calibration offsets applied when "Calibrate" is pressed.

#### How the serial data is applied

```
Raw quaternion (x,y,z,w)
    ↓ multiply by IMU_OFFSET_INV        (cancel 45° mount angle)
    ↓ premultiply by refQuatInv         (cancel starting orientation — calibration)
    ↓ premultiply _axisFlip, multiply _axisFlip  (correct X/Y axis inversion)
    ↓ slerp toward this over multiple frames     (smooth out jitter)
    ↓ apply to pivot.quaternion
```

**IMU_OFFSET_INV** — The IMU board is physically mounted at 45° relative to the robot's forward axis. This correction quaternion (a -45° rotation around Y) cancels that offset.

**refQuatInv** — When you click "Calibrate", the firmware captures the current corrected orientation and inverts it. All future orientations are expressed relative to that reference, so the robot appears in its neutral position.

**Axis flip (conjugation by R_z(π))** — The IMU's X and Y axes are physically wired opposite to the model's frame. A conjugation `R·q·R⁻¹` by a 180° rotation around Z maps X→-X and Y→-Y while leaving Z unchanged. This is the correct way to flip axes for *all* orientations including continuous rotation (a simple sign flip on components would only work for small angles around the identity).

**Slerp** — The smoothing slider controls alpha (0.05–1.0). At alpha=1.0, the model snaps instantly to each new reading. At alpha=0.05, it moves very slowly toward the new orientation. Default 0.25 gives a small amount of damping.

**Pivot Z slider** — Controls the `PIVOT_Z` global variable (OBJ-space Z coordinate). This determines *which point on the 3D model* sits at the scene origin and therefore which point the robot appears to rotate about. Range: −10 (below foot) to +26 (above top). Default −8.5 = foot bottom. Dragging this slider up moves the pivot toward the hip or body, which changes the apparent rotation centre without affecting the quaternion data at all. The slider only changes `obj.position.z = -PIVOT_Z`; the X and Y offset remain fixed at the original foot-bottom values.

#### Model loading details

The OBJ model was exported from Autodesk with Z as the up-axis. Three.js uses Y as up. The `wrapper` object applies a -90° rotation around X to convert between these conventions, so the robot's leg (OBJ Z axis) appears vertical (Three.js Y axis).

The foot bottom in OBJ local coordinates is `(-0.079, 0.048, -8.507)`. The OBJ model is offset so this point sits at the wrapper's origin, which in turn sits at the scene's origin (0,0,0). So the robot pivots about its foot.

---

## 8. Data flow — end to end

```
[Physical world]
      │
      ├──────────────────────────────┬──────────────────────────────────┐
      ▼                              ▼                                  ▼
LSM6DSV16X chip              ARM0/ARM1 encoders              Speed encoders
  Accel + Gyro → SFLP          (pins 22/23, 20/21)            (pins 14/15, 16/17)
  → quaternion → FIFO          → A/B pulse waves               → A/B pulse waves
      │                        → interrupt-counted              → interrupt-counted
      ▼                              ▼                                  ▼
imu.update()                 encoders.update()
  → drains FIFO over I²C      → reads counts, converts to degrees, vel, acc, RPM
  → stores freshest quat       → stores in _angles[], _angularVelDps[], _speedRPM[]
      │                              │
      └──────────────┬───────────────┘
                     ▼
          StateEstimator::tick()  [120 Hz]
            → encoder data    → _state.jointAngles/vel/acc/speedRPM
            → IMU quaternion  → _state.imuQuaternion
            → q.toEuler()    → _state.roll/pitch/yaw (ZYX Euler)
            → micros()       → _state.timestampUs
                     │
          ┌──────────┼──────────────────────┐
          ▼          ▼                      ▼
   safetyISR()    SerialReporter       MotorDriver
   [1 kHz ISR]    [10 Hz print]       [command-driven]
   reads RPY      T:|Q:|RPY:|J:|K:|S:  ARM:/SPR:/SAFE_CLR
   |roll|>45°?         │                    ▲
   → STBY LOW          ▼  (USB 115200)     │
   → SAFE:1       [Computer]           [Computer]
                       │                    │
                       ▼                    │
           visualise_imu.html ──────────────┘
             → parses Q:, RPY:, J: from each line
             → sends ARM:/SPR:/SAFE_CLR commands back
             → applies axis corrections + calibration offset
             → slerps toward corrected quaternion
             → renders the 3D robot with arm rotation
```

---

## 9. Serial output format

The firmware prints one line every 100 ms (10 Hz). Example:

```
T:1234567 | Q:0.00123,0.00456,-0.00012,0.99998 | RPY:0.14,0.52,-0.03 | J:12.3,88.6,0.0 | K:5.40,12.30 | S:120.5,0.0
```

| Part | Example value | Notes |
|---|---|---|
| `T:` | `1234567` | Teensy timestamp in microseconds |
| `Q:` | `0.00123,0.00456,-0.00012,0.99998` | Quaternion x,y,z,w. Near identity when upright. 5 decimal places. |
| `RPY:` | `0.14,0.52,-0.03` | Roll, pitch, yaw in degrees (ZYX Euler). 2 decimal places. |
| `J:` | `12.3,88.6,0.0` | Three joint angles: ARM0, ARM1, LEG. 1 decimal place. |
| `K:` | `5.40,12.30` | ARM1 angular velocity (deg/s) and acceleration (deg/s²). 2 decimal places. |
| `S:` | `120.5,0.0` | Speed encoder RPMs (pins 14/15 and 16/17). 1 decimal place. |

Safety events are printed on separate lines: `SAFE:1` (motors cut) or `SAFE:0` (motors re-enabled via `SAFE_CLR`).

A header is printed on startup:
```
=== MRV Firmware — Serial Reporter ===
Sample rate : 120 Hz
Report rate : 10 Hz
Format: T:<us> | Q:<x>,<y>,<z>,<w> | RPY:<r>,<p>,<y> deg | J:<j0>,<j1>,<j2> deg | S:<rpm0>,<rpm1> | K:<vel_dps>,<acc_dps2>
----------------------------------------------------------------------
```

---

## 10. What is stubbed / not yet built

| Module | Status | What is needed to activate it |
|---|---|---|
| Encoder — ARM0 (index 0) | **Active** — pins 22/23 | PIM604, 50:1 gear ratio. Calibration constants may need empirical tuning. |
| Encoder — ARM1 (index 1) | **Active** — pins 20/21 | PIM604, 50:1 gear ratio. Empirically calibrated (`ENC_ARM1_COUNTS_PER_REV = 12.0f`). |
| Encoder — LEG (index 2) | Stub — 0° | Add pin assignments to `pinout.h`, add constants to `config.h`, add `Encoder` library object and conversion logic in `encoder.cpp`. |
| Speed encoders (2 and 3) | **Active** — pins 14/15, 16/17 | PIM604 (96 CPR). Report shaft RPM. |
| Motor driver (arm + spring) | **Active** | TB6612FNG on pins 8/9/10/11/12 (arm) and 2/7 (spring). Safety cutoff via STBY. |
| Safety ISR | **Active** — 1 kHz | Checks roll/yaw against 45° threshold. Cuts motors via STBY LOW. |
| Filter module (`filters.cpp`) | Empty stub | Not needed yet (SFLP provides filtered output). Reserved for future encoder angle filtering. |
| `getRawAccel()` in IMU | **Implemented** but unused | Reads accelerometer in g. Available for future accel-based tilt computation if needed. |
| INT1 interrupt (`PIN_IMU_INT1`) | Pin shared with spring motor | Interrupt approach abandoned — pin 2 is used for the spring motor. IMU is polled. |

---

## 11. Libraries reference

### STM32duino LSM6DSV16X

**PlatformIO name:** `stm32duino/STM32duino LSM6DSV16X`
**What it does:** Provides a C++ class (`LSM6DSV16XSensor`) that wraps all the low-level I²C/SPI register reads and writes for the ST LSM6DSV16X chip.

Key methods used:
| Method | What it does |
|---|---|
| `begin()` | Reads WHO_AM_I register to verify chip identity |
| `Enable_X()` | Turns on the accelerometer |
| `Enable_G()` | Turns on the gyroscope |
| `Set_X_ODR(hz)` | Sets accelerometer output data rate |
| `Set_X_FS(g)` | Sets accelerometer full-scale range |
| `Set_G_ODR(hz)` | Sets gyroscope output data rate |
| `Set_G_FS(dps)` | Sets gyroscope full-scale range |
| `Set_SFLP_ODR(hz)` | Sets SFLP fusion engine output rate |
| `Enable_Rotation_Vector()` | Starts SFLP and enables game-rotation-vector output to FIFO |
| `FIFO_Set_Watermark_Level(n)` | FIFO threshold level |
| `FIFO_Set_Mode(mode)` | Set FIFO operating mode (stream = continuous) |
| `FIFO_Get_Num_Samples(&n)` | How many samples are in the FIFO |
| `FIFO_Get_Tag(&tag)` | Read the type tag of the next FIFO entry |
| `FIFO_Get_Rotation_Vector(float[4])` | Read quaternion from FIFO: [x, y, z, w] |
| `FIFO_Get_Data(buf)` | Read and discard a FIFO entry of unknown type |
| `Reset_SFLP()` | Reset the fusion engine (use for recalibration) |
| `Get_X_Axes(int32_t[3])` | Read current accelerometer output in mg (milligravity) |
| `Enable_Rotation_Vector()` | Start SFLP game-rotation-vector output to FIFO |

Return code: `LSM6DSV16X_OK = 0` on success, nonzero on error.

---

### paulstoffregen/Encoder

**PlatformIO name:** `paulstoffregen/Encoder`
**What it does:** Reads quadrature encoders using hardware interrupts, giving accurate counts without the CPU having to continuously poll the pins. Heavily optimised for Teensy.

Key methods used:

| Method | What it does |
|---|---|
| `Encoder enc(pinA, pinB)` | Constructor — attaches interrupt handlers to both pins immediately |
| `enc.read()` | Returns the current signed count as `int32_t`. Counts up or down depending on direction. |
| `enc.write(n)` | Sets the current count to `n`. Used in `begin()` to zero the angle at startup. |

**Important:** The library's class is also called `Encoder`. To avoid a name collision with the project's own encoder wrapper, the wrapper class is named `JointEncoders`. Inside `encoder.cpp`, `Encoder` always refers to the library class.

The firmware creates four `Encoder` objects: `s_arm0` (pins 22/23), `s_arm1` (pins 20/21), `s_speed2` (pins 14/15), and `s_speed3` (pins 16/17).

---

### Arduino / Teensyduino core

Built in to every Arduino/Teensy project. Used functions:

| Function / class | Meaning |
|---|---|
| `setup()`, `loop()` | Entry points for every Arduino sketch |
| `pinMode(pin, mode)` | Configure a pin as INPUT or OUTPUT |
| `digitalWrite(pin, value)` | Set a digital pin HIGH (3.3V) or LOW (0V) |
| `delay(ms)` | Block the CPU for ms milliseconds |
| `millis()` | Milliseconds since power-on (32-bit, wraps after ~49 days) |
| `micros()` | Microseconds since power-on (32-bit, wraps after ~70 minutes) |
| `Serial.begin(baud)` | Open the USB serial port |
| `Serial.print(x)` | Print a value (no newline) |
| `Serial.println(x)` | Print a value and newline |
| `Serial.flush()` | Wait until all data has been sent |
| `Wire` | The I²C bus object (from `<Wire.h>`) |
| `Wire.begin()` | Start the I²C bus |
| `Wire.setClock(hz)` | Set I²C bus frequency |
| `IntervalTimer` | Teensy hardware timer (4 available, from `<IntervalTimer.h>`) |
| `IntervalTimer::begin(fn, us)` | Call `fn` every `us` microseconds |
| `F("string")` | Store a string literal in flash memory |
| `String` | Arduino string class (heap-allocated) |

---

### Three.js (browser visualiser)

Loaded via importmap CDN — no installation needed. Version 0.164.1.

| Import | What it provides |
|---|---|
| `three` | Core 3D engine: Scene, Camera, Renderer, Quaternion, etc. |
| `three/addons/loaders/OBJLoader.js` | Loads Wavefront `.obj` files |
| `three/addons/loaders/MTLLoader.js` | Loads `.mtl` material files for the OBJ |
| `three/addons/controls/OrbitControls.js` | Mouse-driven camera controls |

---

### Python visualiser dependencies

| Package | What it does |
|---|---|
| `pyserial` | Reads from USB serial ports |
| `numpy` | Fast numerical arrays; used for quaternion→matrix conversion |
| `matplotlib` | Plots and animation |
| `mpl_toolkits.mplot3d` | 3D axes for matplotlib |
| `threading` | Runs the serial reader in a background thread |

Install: `pip install pyserial numpy matplotlib`

---

*This README is kept up to date as the project evolves. If you notice anything that is out of date or unclear, edit it alongside the code change that prompted the confusion.*

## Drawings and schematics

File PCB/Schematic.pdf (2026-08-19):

+

_

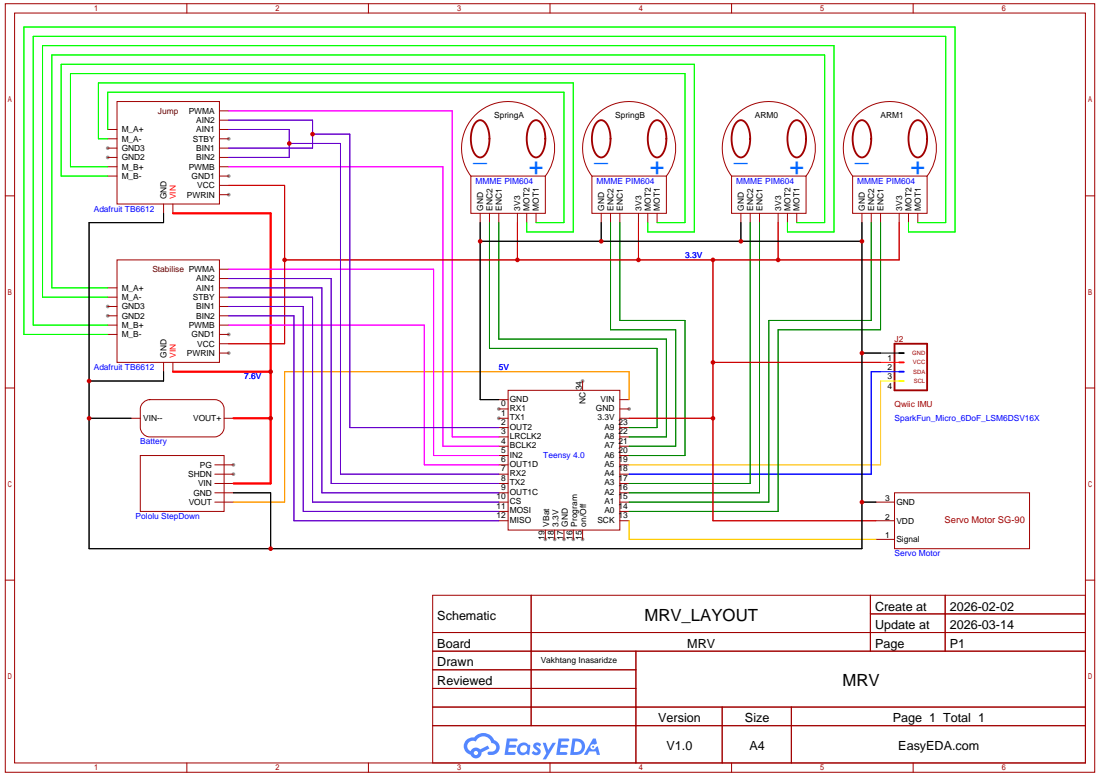
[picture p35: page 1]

Schematic | MRV_LAYOUT | Create at | 2026-02-02

Update at | 2026-03-14

Board | MRV | Page | P1
Drawn | Vakhtang Inasaridze | MRV
Reviewed

Version | Size | Page 1 Total 1
V1.0 | A4 | EasyEDA.com

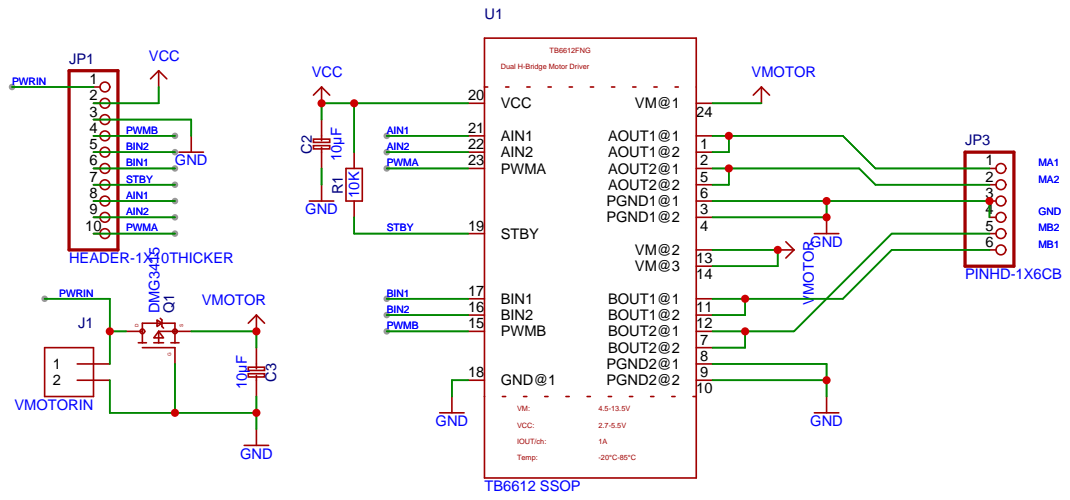
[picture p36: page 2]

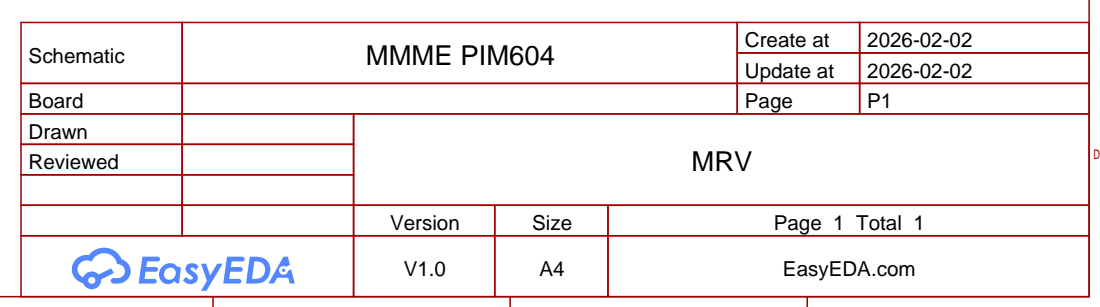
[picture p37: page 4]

Schematic | MMME PIM604 | Create at | 2026-02-02

Update at | 2026-02-02

Board | | Page | P1
Drawn | | MRV
Reviewed

Schematic | MMME PIM604 | Create at | 2026-02-02

Update at | 2026-02-02

Board | | Page | P1
Drawn | | MRV
Reviewed

Schematic | MMME PIM604 | Create at | 2026-02-02

Update at | 2026-02-02

Board | | Page | P1
Drawn | | MRV
Reviewed

Schematic | MMME PIM604 | Create at | 2026-02-02

Update at | 2026-02-02

Board | | Page | P1
Drawn | | MRV
Reviewed

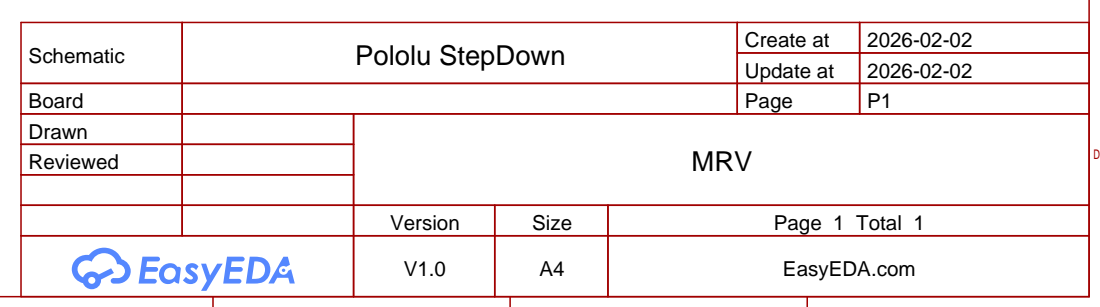
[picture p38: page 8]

Schematic | Pololu StepDown | Create at | 2026-02-02

Update at | 2026-02-02

Board | | Page | P1
Drawn | | MRV
Reviewed

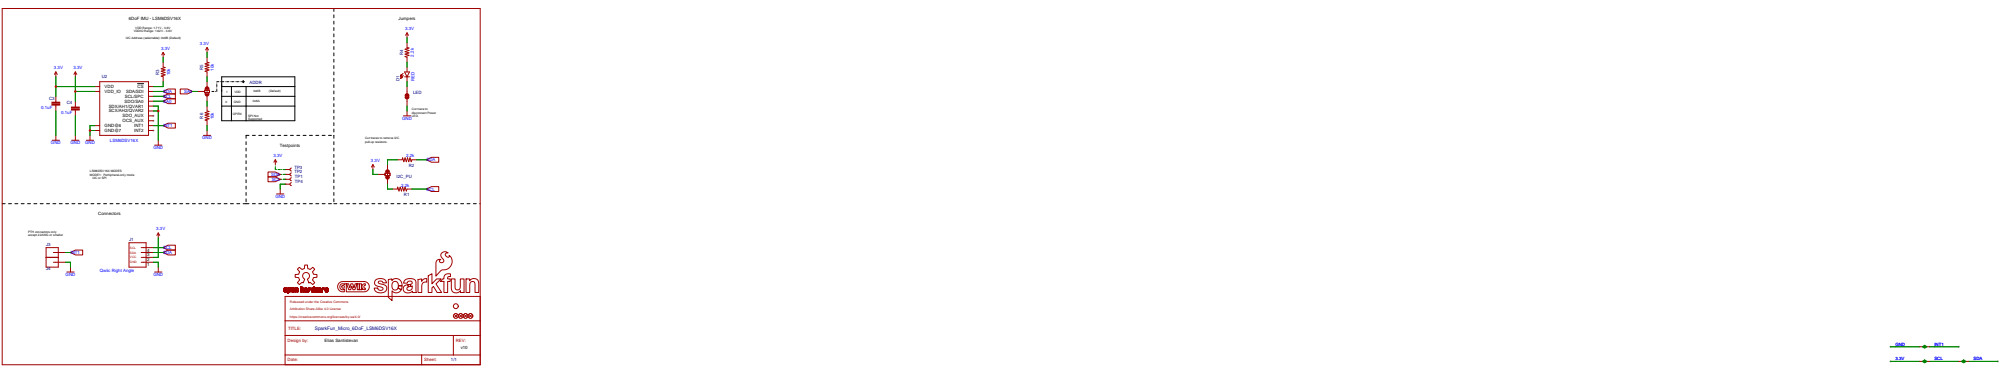
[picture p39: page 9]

SDA/SDI SCL/SPC

GND | SPI Not Supported 10 0x6A

OPEN

Cut traces to remove I2C
pull-up resistors.

LSM6DSV16X MODES MODE1: Perhipheral-only mode

PTH connectors only accept 22AWG or smaller

Released under the Creative Commons
Attribution Share-Alike 4.0 License
https://creativecommons.org/licenses/by-sa/4.0/
TITLE:

Design by: Elias Santistevan | REV: v10

Date: | Sheet: 1/1

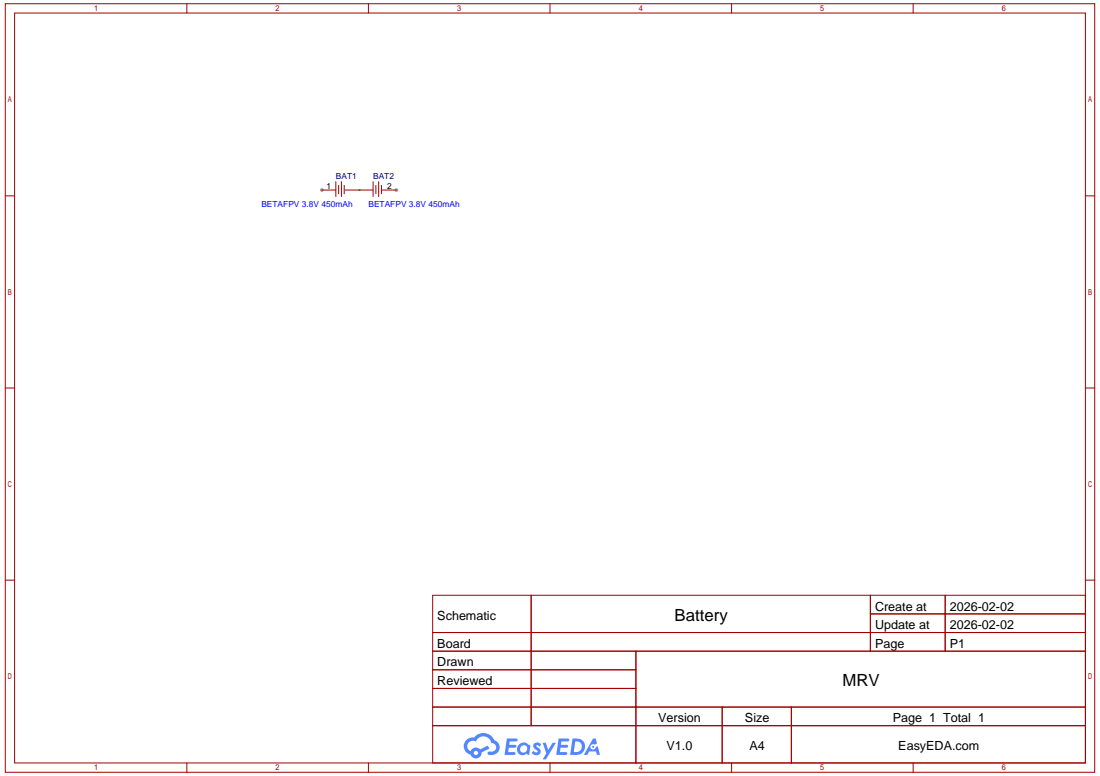
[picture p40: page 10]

Schematic | Battery | Create at | 2026-02-02

Update at | 2026-02-02

Board | | Page | P1
Drawn | | MRV
Reviewed

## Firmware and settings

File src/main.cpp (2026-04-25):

/**
 * @file    main.cpp
 * @brief   Firmware entry point for the MRV robot controller (Teensy 4.0).
 * @details setup() and loop() only — no hardware access, no logic.
 *          All work is delegated to the appropriate subsystem objects:
 *            - IMU          reads the LSM6DSV16X SFLP quaternion.
 *            - StateEstimator  runs at IMU_SAMPLE_RATE_HZ via IntervalTimer,
 *                              populates RobotState each tick.
 *            - SerialReporter  prints RobotState at SERIAL_REPORT_RATE_HZ.
 *            - MotorDriver     drives arm and spring TB6612 H-bridges with
 *                              a safety cutoff triggered by tilt (roll / yaw).
 *            - safetyISR()     IntervalTimer ISR at SAFETY_CHECK_RATE_HZ that
 *                              cuts motors immediately on tilt — independent of
 *                              I2C / serial load in the main loop.
 *
 *          Fault handling: if begin() fails on any subsystem, the firmware
 *          halts and blinks PIN_LED with a distinct pattern so the failure is
 *          visible without a debugger.
 *
 *          Incoming serial commands (from visualiser):
 *            ARM:<a>,<b>\n          — arm motor speeds in MANUAL mode (-255…255)
 *            SPR:<speed>\n          — spring motor speed (-255…255)
 *            SAFE_CLR\n             — re-enable motors after safety trip
 *            CTRL:<0/1/2>\n         — switch mode: 0=Manual, 1=AttitudePID, 2=RevSync
 *            PIDA:<kp>,<ki>,<kd>\n  — Motor A PID gains
 *            PIDB:<kp>,<ki>,<kd>\n  — Motor B PID gains
 *            AXIS:<0/1/2>\n         — PID feedback axis: 0=roll, 1=pitch, 2=yaw
 *            SETP:<deg>\n           — attitude PID setpoint in degrees
 *            REV:<n>,<rpm>\n        — start revolution sync (N revs at RPM)
 *            DIRA:<0/1>\n           — Motor A direction flip
 *            DIRB:<0/1>\n           — Motor B direction flip
 *
 * @inputs  None — all hardware is abstracted behind the subsystem classes.
 * @outputs SerialReporter + safety-event lines "SAFE:1\n" / "SAFE:0\n".
 * @deps    hardware/imu.h, hardware/encoder.h, hardware/motor_driver.h,
 *          hardware/motor_controller.h, hardware/pinout.h,
 *          state/state_estimator.h, comms/serial_reporter.h,
 *          config/config.h, <Arduino.h>
 */

#include <Arduino.h>
#include <Servo.h>

#include "config/config.h"
#include "hardware/pinout.h"
#include "hardware/imu.h"
#include "hardware/encoder.h"
#include "hardware/motor_driver.h"
#include "hardware/motor_controller.h"
#include "state/state_estimator.h"
#include "comms/serial_reporter.h"

// =============================================================================
// Subsystem objects  (static storage — constructed before setup())
// =============================================================================

static IMU             imu;
static JointEncoders   encoders;
static StateEstimator  stateEstimator(imu, encoders);
static SerialReporter  reporter;
static MotorDriver     motors;
static MotorController motorCtrl;

// =============================================================================
// Servo — manually triggered via TAP serial command
// =============================================================================

static Servo s_servo;

/// How long to wait for the servo to physically reach 0° before snapping back (ms).
static constexpr uint32_t kServoTransitMs = 800u;

static bool     s_servoActive  = false;
static uint32_t s_servoTimerMs = 0u;

// =============================================================================
// Safety IntervalTimer — runs at SAFETY_CHECK_RATE_HZ independently of loop()
// =============================================================================

static IntervalTimer     s_safetyTimer;
static volatile bool     s_safetyJustTripped = false;

static void safetyISR()
{
    const RobotState& st = stateEstimator.getState();
    // Trip on physical tilt axes: roll (left/right) and pitch (forward/back).
    // In R/Y/P display mode these show as displayed Roll and displayed Yaw.
    if (fabsf(st.roll) > SAFETY_TILT_DEG || fabsf(st.pitch) > SAFETY_TILT_DEG) {
        if (!motorCtrl.isSafetyTripped()) {
            motorCtrl.safetyStop();
            s_safetyJustTripped = true;
        }
    }
}

// =============================================================================
// Incoming serial command parser
// =============================================================================

namespace {
    char    s_cmdBuf[32];
    uint8_t s_cmdIdx = 0u;

    void parseCommand(const char* cmd)
    {
        // ── ARM: manual arm PWM (only active in MANUAL mode) ──────────────────
        if (strncmp(cmd, "ARM:", 4) == 0) {
            int16_t a = 0, b = 0;
            if (sscanf(cmd + 4, "%hd,%hd", &a, &b) == 2) {
                motorCtrl.setManualA(a);
                motorCtrl.setManualB(b);
            }

        // ── SPR: spring motor (unchanged) ─────────────────────────────────────
        } else if (strncmp(cmd, "SPR:", 4) == 0) {
            int16_t s = 0;
            if (sscanf(cmd + 4, "%hd", &s) == 1) {
                motors.setSpring(s);
            }

        // ── CTRL: switch control mode (0=Manual, 1=AttitudePID, 2=RevSync) ───
        } else if (strncmp(cmd, "CTRL:", 5) == 0) {
            int m = 0;
            if (sscanf(cmd + 5, "%d", &m) == 1) {
                motorCtrl.setMode(static_cast<CtrlMode>(m));
            }

        // ── PIDA: Motor A PID gains <kp>,<ki>,<kd> ────────────────────────────
        } else if (strncmp(cmd, "PIDA:", 5) == 0) {
            float kp = 0.0f, ki = 0.0f, kd = 0.0f;
            if (sscanf(cmd + 5, "%f,%f,%f", &kp, &ki, &kd) == 3) {
                motorCtrl.setGainsA(kp, ki, kd);
            }

        // ── PIDB: Motor B PID gains <kp>,<ki>,<kd> ────────────────────────────
        } else if (strncmp(cmd, "PIDB:", 5) == 0) {
            float kp = 0.0f, ki = 0.0f, kd = 0.0f;
            if (sscanf(cmd + 5, "%f,%f,%f", &kp, &ki, &kd) == 3) {
                motorCtrl.setGainsB(kp, ki, kd);
            }

        // ── AXIS: PID feedback axis (0=roll, 1=pitch, 2=yaw) ─────────────────
        } else if (strncmp(cmd, "AXIS:", 5) == 0) {
            int ax = 0;
            if (sscanf(cmd + 5, "%d", &ax) == 1) {
                motorCtrl.setPIDAxis(static_cast<uint8_t>(ax));
            }

        // ── SETP: attitude PID setpoint in degrees ────────────────────────────
        } else if (strncmp(cmd, "SETP:", 5) == 0) {
            float deg = 0.0f;
            if (sscanf(cmd + 5, "%f", &deg) == 1) {
                motorCtrl.setAttitudeSetpoint(deg);
            }

        // ── REV: start revolution sync <n_revs>,<rpm> ────────────────────────
        } else if (strncmp(cmd, "REV:", 4) == 0) {
            float nRevs = 0.0f, rpm = 0.0f;
            if (sscanf(cmd + 4, "%f,%f", &nRevs, &rpm) == 2) {
                motorCtrl.startRevSync(rpm, nRevs);
            }

        // ── DIRA / DIRB: per-motor direction flip (0=normal, 1=flipped) ──────
        } else if (strncmp(cmd, "DIRA:", 5) == 0) {
            int f = 0;
            if (sscanf(cmd + 5, "%d", &f) == 1) {
                motorCtrl.setDirFlipA(f != 0);
            }
        } else if (strncmp(cmd, "DIRB:", 5) == 0) {
            int f = 0;
            if (sscanf(cmd + 5, "%d", &f) == 1) {
                motorCtrl.setDirFlipB(f != 0);
            }

        // ── SAFE_CLR: re-enable motors after safety trip ──────────────────────
        } else if (strcmp(cmd, "SAFE_CLR") == 0) {
            motorCtrl.clearSafety();
            Serial.println(F("SAFE:0"));

        // ── TAP: manually trigger servo ───────────────────────────────────────
        } else if (strcmp(cmd, "TAP") == 0) {
            if (!s_servoActive) {
                s_servoActive  = true;
                s_servoTimerMs = millis();
                s_servo.write(0);
                Serial.println(F("TAP: servo -> 0 deg"));
            }
        }
    }

    void readSerialCommands()
    {
        while (Serial.available()) {
            const char c = static_cast<char>(Serial.read());
            if (c == '\n' || c == '\r') {
                if (s_cmdIdx > 0u) {
                    s_cmdBuf[s_cmdIdx] = '\0';
                    parseCommand(s_cmdBuf);
                    s_cmdIdx = 0u;
                }
            } else if (s_cmdIdx < static_cast<uint8_t>(sizeof(s_cmdBuf) - 1u)) {
                s_cmdBuf[s_cmdIdx++] = c;
            }
        }
    }
}


// =============================================================================
// Internal helpers
// =============================================================================

/**
 * @brief  Infinite fault loop — blinks PIN_LED at the given period and
 *         repeatedly prints msg to Serial.
 *         Halts all other firmware activity.
 * @param  msg         Error description to print on Serial.
 * @param  blinkMs     Half-period of the LED blink in milliseconds.
 */
static void faultHalt(const char* msg, uint32_t blinkMs)
{
    // Serial may not be open yet; flush whatever we can.
    Serial.println(msg);
    Serial.flush();

    while (true) {
        digitalWrite(PIN_LED, HIGH);
        delay(blinkMs);
        digitalWrite(PIN_LED, LOW);
        delay(blinkMs);
    }
}

// =============================================================================
// setup()
// =============================================================================

void setup()
{
    // ── Status LED ────────────────────────────────────────────────────────────
    pinMode(PIN_LED, OUTPUT);
    digitalWrite(PIN_LED, LOW);

    // ── Serial ────────────────────────────────────────────────────────────────
    // reporter.begin() calls Serial.begin(); call it before any Serial prints.
    reporter.begin(115200u);

    // Wait up to 3 s for a USB serial connection (useful during development).
    // Remove this block for standalone (non-tethered) deployment.
    const uint32_t serialWaitStart = millis();
    while (!Serial && (millis() - serialWaitStart) < 3000u) { /* wait */ }

    Serial.println(F("MRV firmware starting…"));

    // ── Motor driver ─────────────────────────────────────────────────────────
    motors.begin();
    motorCtrl.begin(motors, encoders);
    Serial.println(F("Motors: OK"));

    // ── Encoders ──────────────────────────────────────────────────────────────
    // Encoder begin() resets the count to zero (power-on position = 0°).
    // It does not halt on failure — the robot can still run with IMU only.
    if (encoders.begin()) {
        Serial.println(F("Encoders: ARM1 active on pins 20/21"));
    } else {
        Serial.println(F("Encoders: begin() failed — joint angles will read 0°"));
    }

    // ── IMU ───────────────────────────────────────────────────────────────────
    if (!imu.begin()) {
        // Short rapid blink (200 ms) = IMU fault.
        faultHalt("FAULT: IMU begin() failed — check wiring and config.h",
                  200u);
    }
    Serial.print(F("IMU: "));
    Serial.println(imu.getStatusString());

    // ── State estimator ───────────────────────────────────────────────────────
    if (!stateEstimator.begin()) {
        // Medium blink (500 ms) = timer resource exhausted.
        faultHalt("FAULT: StateEstimator begin() failed — no IntervalTimer available",
                  500u);
    }
    Serial.print(F("StateEstimator: running at "));
    Serial.print(IMU_SAMPLE_RATE_HZ);
    Serial.println(F(" Hz"));


    // ── Safety monitor ────────────────────────────────────────────────────────
    s_safetyTimer.begin(safetyISR, 1000000u / SAFETY_CHECK_RATE_HZ);
    Serial.println(F("Safety: armed (roll/yaw tilt check at 1 kHz)"));

    // ── Servo ─────────────────────────────────────────────────────────────────
    s_servo.attach(PIN_SERVO);
    s_servo.write(90);
    Serial.println(F("Servo: attached on pin 28, parked at 90 deg"));

    // ── Ready ─────────────────────────────────────────────────────────────────
    digitalWrite(PIN_LED, HIGH);
    Serial.println(F("Setup complete — entering main loop."));
}

// =============================================================================
// loop()
// =============================================================================

void loop()
{
    // ── Parse any incoming motor/safety commands from the visualiser ──────────
    readSerialCommands();

    // ── Notify visualiser of safety trip (deferred from ISR) ─────────────────
    if (s_safetyJustTripped) {
        s_safetyJustTripped = false;
        Serial.println(F("SAFE:1"));
    }

    // ── Process one pending IMU sample (if the IntervalTimer has fired) ───────
    stateEstimator.tick();

    // ── Servo snap-back ───────────────────────────────────────────────────────
    if (s_servoActive && (millis() - s_servoTimerMs >= kServoTransitMs)) {
        s_servo.write(90);
        s_servoActive = false;
        Serial.println(F("TAP: servo -> 90 deg (snap back)"));
    }

    // ── Print the current state to Serial if the report interval has elapsed ──
    const RobotState& st = stateEstimator.getState();
    motorCtrl.tick(st, 1.0f / static_cast<float>(IMU_SAMPLE_RATE_HZ));
    reporter.update(st, motorCtrl);
}

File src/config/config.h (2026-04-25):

/**
 * @file    config.h
 * @brief   Global compile-time configuration constants for the MRV firmware.
 * @details Single source of truth for every tunable parameter in the project.
 *          No magic numbers belong anywhere else in the codebase.
 *          All values are constexpr — zero runtime cost, full type safety.
 * @inputs  None — this file has no dependencies.
 * @outputs constexpr constants consumed by all other modules.
 * @deps    None.
 */

#pragma once

#include <stdint.h>

// =============================================================================
// Sample and report rates
// =============================================================================

/// State estimator sample rate in Hz.
/// Drives the IntervalTimer period inside StateEstimator.
/// Must not exceed the configured SFLP_ODR_HZ.
constexpr uint16_t IMU_SAMPLE_RATE_HZ = 120u;

/// Serial reporter output rate in Hz.
/// Must be <= IMU_SAMPLE_RATE_HZ.  Controls how often SerialReporter prints.
constexpr uint16_t SERIAL_REPORT_RATE_HZ = 10u;

// =============================================================================
// Accelerometer / gyroscope ODR and full-scale range
// =============================================================================

/// Accelerometer output data rate in Hz.
/// Should match SFLP_ODR_HZ so the fusion engine is never starved.
constexpr float IMU_ACCEL_ODR_HZ = 120.0f;

/// Accelerometer full-scale range in ±g.  Valid: 2, 4, 8, 16.
/// ±2g gives the best resolution for a slow robot.
constexpr uint8_t IMU_ACCEL_FS_G = 2u;

/// Gyroscope output data rate in Hz.
/// Should match SFLP_ODR_HZ.
constexpr float IMU_GYRO_ODR_HZ = 120.0f;

/// Gyroscope full-scale range in ±dps.  Valid: 125, 250, 500, 1000, 2000, 4000.
/// ±250 dps balances resolution with headroom for fast motions.
/// Lower values improve bias estimation and reduce drift.
constexpr uint16_t IMU_GYRO_FS_DPS = 250u;

// =============================================================================
// SFLP (Sensor Fusion Low Power) engine configuration
// =============================================================================

/// SFLP output data rate in Hz.
/// Valid values for LSM6DSV16X: 15, 30, 60, 120.
/// Set to the maximum supported rate to minimise fusion latency.
constexpr float SFLP_ODR_HZ = 120.0f;

/// Enable onboard gyroscope bias estimation within the SFLP engine.
/// 1 = enabled (recommended for long-run stability), 0 = disabled.
constexpr uint8_t SFLP_ENABLE_GBIAS = 1u;

/// FIFO watermark level — number of SFLP game-rotation-vector samples to
/// accumulate before the firmware reads the FIFO.
/// 1 minimises latency; increase only if I2C bus overhead is a concern.
constexpr uint16_t IMU_FIFO_WATERMARK = 1u;

// =============================================================================
// Encoder / joint configuration
// =============================================================================

/// Number of independently encoded robot joints.
///   0 — ARM     (left arm)
///   1 — ARM(1)  (right arm)  ← active encoder, pins 20/21
///   2 — LEG     (vertical slide)
constexpr uint8_t NUM_ENCODER_JOINTS = 3u;

/// ARM1 (joint index 1) encoder — quadrature counts per full encoder shaft revolution.
/// Empirically calibrated: with a confirmed 50:1 gear ratio, one full arm revolution
/// measured 22°, implying the encoder produces only ~12 counts/rev rather than the
/// nominal 96 (24 PPR × 4).  Possible causes: encoder outputs non-quadrature signal,
/// channel B wiring issue, or non-standard PPR.  Adjust until one arm rev = 360°.
constexpr float ENC_ARM1_COUNTS_PER_REV = 12.0f; //DO NOT TOUCH

/// ARM1 gear ratio: encoder shaft revolutions per joint output revolution.
/// Confirmed by user as 50:1.
constexpr float ENC_ARM1_GEAR_RATIO = 50.0f; //DO NOT TOUCH

/// ARM (joint 0) calibration angle at begin() — physical rest position in degrees.
constexpr float ENC_ARM0_INIT_DEG = 0.0f;

/// ARM(1) (joint 1) calibration angle at begin() — physical rest position in degrees.
constexpr float ENC_ARM1_INIT_DEG = 90.0f;

// =============================================================================
// ARM (joint 0) encoder — enable once wired
// =============================================================================

/// Uncomment to activate the ARM (joint 0) encoder driver.
/// Also set PIN_ENC_ARM0_A/B in pinout.h before enabling.
#define USE_ARM0_ENCODER

/// Counts per encoder shaft revolution — same model as ARM(1), placeholder value.
/// Tune empirically once wired (like ENC_ARM1_COUNTS_PER_REV).
constexpr float ENC_ARM0_COUNTS_PER_REV = 12.0f;  // tune when wired

/// Gear ratio — placeholder, confirm with hardware.
constexpr float ENC_ARM0_GEAR_RATIO = 50.0f;  // tune when wired

/// Angle-to-count scalar — analogous to the 359.32f in the ARM(1) formula.
/// Tune manually until one full arm revolution reads exactly 360°.
constexpr float ENC_ARM0_SCALAR = 360.0f;  // tune when wired
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

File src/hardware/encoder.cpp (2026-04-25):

/**
 * @file    encoder.cpp
 * @brief   Joint encoder driver implementation using paulstoffregen/Encoder.
 * @details ARM0 (joint 0, pins 17/16) and ARM1 (joint 1, pins 14/15) are both
 *          decoded in full 4× quadrature mode, reporting position (degrees),
 *          angular velocity (deg/s), and angular acceleration (deg/s²).
 *
 *          encoderSpeedRPM[] is derived from joint angular velocity — no separate
 *          encoder objects are needed for RPM since the joint encoders already
 *          compute smoothed velocity:
 *            RPM = angularVelDps / 6.0  (= deg/s ÷ 360 × 60)
 *            speedRPM[0] ← ARM1 arm-shaft RPM  (Motor B feedback)
 *            speedRPM[1] ← ARM0 arm-shaft RPM  (Motor A feedback)
 *
 *          Counts-to-degrees for ARM(1):
 *            degrees = count × 359.32 / (ENC_ARM1_COUNTS_PER_REV × ENC_ARM1_GEAR_RATIO)
 *
 *          Angular velocity (sliding window + EMA):
 *            rawVel = (angle_now − angle[ENC_VEL_WINDOW ticks ago]) / window_dt
 *            vel    = ENC_VEL_ALPHA × rawVel + (1 − α) × vel_prev
 *
 *          Angular acceleration:
 *            acc (deg/s²) = (vel_now − vel_prev) / one_tick_dt
 *
 * @inputs  ARM0:  A/B on PIN_ENC_ARM0_A (17) and PIN_ENC_ARM0_B (16).
 *          ARM1:  A/B on PIN_ENC_ARM1_A (14) and PIN_ENC_ARM1_B (15).
 * @outputs Angles + kinematics via getAngle(), getAngularVelDps(), getAngularAccDps2().
 *          Arm-shaft RPM via getSpeedRPM().
 * @deps    hardware/encoder.h, hardware/pinout.h, config/config.h,
 *          <Encoder.h> (paulstoffregen/Encoder library)
 */

#include <Encoder.h>                 // paulstoffregen's quadrature library

#include "hardware/encoder.h"
#include "hardware/pinout.h"
#include "config/config.h"

// =============================================================================
// Module-level encoder pointers (constructed in begin() after USB init)
// =============================================================================

// Encoder objects are heap-constructed in begin() rather than at static init
// time.  Static construction of Encoder objects runs before Teensyduino's USB
// initialisation and was found to crash the firmware (8-blink Teensyduino
// fault pattern) on Teensy 4.0.  Deferring to begin() avoids this.

static Encoder* s_arm1 = nullptr;

#ifdef USE_ARM0_ENCODER
static Encoder* s_arm0 = nullptr;
#endif

// =============================================================================
// Constructor
// =============================================================================

JointEncoders::JointEncoders()
    : _prevSpeedUs(0u),
      _histIdx(0u), _histFull(false)
{
    for (uint8_t i = 0u; i < NUM_ENCODER_JOINTS; ++i) {
        _angles[i]         = 0.0f;
        _angularVelDps[i]  = 0.0f;
        _angularAccDps2[i] = 0.0f;
    }
    for (uint8_t s = 0u; s < ENC_VEL_WINDOW; ++s) {
        _timeHistory[s] = 0u;
        for (uint8_t j = 0u; j < NUM_ENCODER_JOINTS; ++j) {
            _angleHistory[j][s] = 0.0f;
        }
    }
    for (uint8_t i = 0u; i < NUM_SPEED_ENCODERS; ++i) {
        _speedRPM[i] = 0.0f;
    }
}

// =============================================================================
// JointEncoders::begin()
// =============================================================================

bool JointEncoders::begin()
{
    // ── Construct encoder objects here (deferred from static init) ────────────
    // Constructing Encoder objects at static init time caused a Teensyduino
    // hard-fault (8-blink) on Teensy 4.0 because the interrupt infrastructure
    // is not yet fully initialised before setup() runs.
    s_arm1 = new Encoder(PIN_ENC_ARM1_A, PIN_ENC_ARM1_B);

#ifdef USE_ARM0_ENCODER
    s_arm0 = new Encoder(PIN_ENC_ARM0_A, PIN_ENC_ARM0_B);
#endif

    // ── ARM(1) — set count to match physical rest angle ───────────────────────
    // Derived by inverting: angle = count × 359.32 / (CPR × ratio)
    const int32_t arm1InitCount = static_cast<int32_t>(
        ENC_ARM1_INIT_DEG * ENC_ARM1_COUNTS_PER_REV * ENC_ARM1_GEAR_RATIO / 359.32f
    );
    s_arm1->write(arm1InitCount);

#ifdef USE_ARM0_ENCODER
    // ── ARM — set count to match physical rest angle ──────────────────────────
    const int32_t arm0InitCount = static_cast<int32_t>(
        ENC_ARM0_INIT_DEG * ENC_ARM0_COUNTS_PER_REV * ENC_ARM0_GEAR_RATIO / ENC_ARM0_SCALAR
    );
    s_arm0->write(arm0InitCount);
#endif

    // Initialise stored state from calibrated starting positions.
    for (uint8_t i = 0u; i < NUM_ENCODER_JOINTS; ++i) {
        _angles[i]         = 0.0f;
        _angularVelDps[i]  = 0.0f;
        _angularAccDps2[i] = 0.0f;
    }
    _angles[0] = ENC_ARM0_INIT_DEG;
    _angles[1] = ENC_ARM1_INIT_DEG;

    // Pre-fill ring buffer with the calibrated angles so the first update()
    // computes a valid (zero) velocity immediately rather than waiting for
    // ENC_VEL_WINDOW ticks.  All slots share the same timestamp — the winDt
    // guard in update() prevents a divide-by-zero on the first real tick.
    const uint32_t t0 = micros();
    for (uint8_t s = 0u; s < ENC_VEL_WINDOW; ++s) {
        _timeHistory[s]    = t0;
        _angleHistory[0][s] = ENC_ARM0_INIT_DEG;
        _angleHistory[1][s] = ENC_ARM1_INIT_DEG;
    }
    _histIdx  = 0u;
    _histFull = true;

    for (uint8_t i = 0u; i < NUM_SPEED_ENCODERS; ++i) {
        _speedRPM[i] = 0.0f;
    }

    _prevSpeedUs = micros();

    return true;
}

// =============================================================================
// JointEncoders::update()
// =============================================================================
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

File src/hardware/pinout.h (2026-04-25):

/**
 * @file    pinout.h
 * @brief   All Teensy 4.0 pin assignments for the MRV project.
 * @details Single source of truth for every physical pin number.
 *          No pin numbers appear anywhere else in the codebase —
 *          every driver must import this header instead of using literals.
 * @inputs  None.
 * @outputs constexpr pin-number constants consumed by hardware drivers.
 * @deps    <Arduino.h>  (for uint8_t in the Arduino build environment)
 */

#pragma once

#include <Arduino.h>

// =============================================================================
// IMU — LSM6DSV16X
// =============================================================================

/// INT1 output from the LSM6DSV16X (unused — firmware polls FIFO).
constexpr uint8_t PIN_IMU_INT1   = 2u;

/// SPI chip-select (unused — firmware uses I2C).
constexpr uint8_t PIN_IMU_SPI_CS = 10u;

// =============================================================================
// ARM0 motor — TB6612FNG channel A
// =============================================================================

constexpr uint8_t PIN_ARM0_AIN1 = 8u;   ///< ARM0 direction 1  (TB6612 AIN1)
constexpr uint8_t PIN_ARM0_AIN2 = 9u;   ///< ARM0 direction 2  (TB6612 AIN2)
constexpr uint8_t PIN_ARM0_PWMA = 5u;   ///< ARM0 speed        (TB6612 PWMA)

// =============================================================================
// ARM1 motor — TB6612FNG channel B  (shared STBY with ARM0)
// =============================================================================

constexpr uint8_t PIN_ARM1_BIN1 = 11u;  ///< ARM1 direction 1  (TB6612 BIN1)
constexpr uint8_t PIN_ARM1_BIN2 = 12u;  ///< ARM1 direction 2  (TB6612 BIN2)
constexpr uint8_t PIN_ARM1_PWMB = 6u;   ///< ARM1 speed        (TB6612 PWMB)

constexpr uint8_t PIN_ARM_STBY  = 10u;  ///< Standby shared by ARM0 + ARM1 — LOW disables both

// =============================================================================
// Spring motor A — TB6612FNG channel A
// =============================================================================

constexpr uint8_t PIN_SPRA_AIN1 = 7u;   ///< SpringA direction 1  (TB6612 AIN1)
constexpr uint8_t PIN_SPRA_AIN2 = 2u;   ///< SpringA direction 2  (TB6612 AIN2)
constexpr uint8_t PIN_SPRA_PWMA = 3u;   ///< SpringA speed        (TB6612 PWMA)

// =============================================================================
// Spring motor B — TB6612FNG channel B  (IN pins tied to SpringA)
// =============================================================================

constexpr uint8_t PIN_SPRB_BIN1 = 2u;   ///< SpringB direction 1  (TB6612 BIN1) — tied to PIN_SPRA_AIN2
constexpr uint8_t PIN_SPRB_BIN2 = 7u;   ///< SpringB direction 2  (TB6612 BIN2) — tied to PIN_SPRA_AIN1
constexpr uint8_t PIN_SPRB_PWMB = 4u;   ///< SpringB speed        (TB6612 PWMB)

// =============================================================================
// Joint encoders — quadrature A/B channels
// =============================================================================

constexpr uint8_t PIN_ENC_ARM0_A = 17u;  ///< ARM0 encoder channel A
constexpr uint8_t PIN_ENC_ARM0_B = 16u;  ///< ARM0 encoder channel B

constexpr uint8_t PIN_ENC_ARM1_A = 14u;  ///< ARM1 encoder channel A
constexpr uint8_t PIN_ENC_ARM1_B = 15u;  ///< ARM1 encoder channel B

constexpr uint8_t PIN_ENC_SPRA_A = 20u;  ///< SpringA encoder channel A
constexpr uint8_t PIN_ENC_SPRA_B = 21u;  ///< SpringA encoder channel B

constexpr uint8_t PIN_ENC_SPRB_A = 22u;  ///< SpringB encoder channel A
constexpr uint8_t PIN_ENC_SPRB_B = 23u;  ///< SpringB encoder channel B

// =============================================================================
// General / status
// =============================================================================

constexpr uint8_t PIN_LED = 13u;  ///< Teensy 4.0 onboard LED — startup + fault blink

// =============================================================================
// Servo
// =============================================================================

constexpr uint8_t PIN_SERVO = 28u;  ///< Tap-triggered servo signal output

// =============================================================================
// Voltage sensor — analogue input
// =============================================================================

/// Voltage divider: 24 kΩ top (two 12 kΩ) + 12 kΩ bottom across battery.
/// V_batt = V_pin × 3.  At 8.4 V: V_pin = 2.8 V — within 3.3 V ADC limit.
constexpr uint8_t PIN_VOLTAGE = 26u;

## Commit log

2026-04-25 Initial release
    [Battery.stp, CAM.stp, DC+motor.stp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]
2026-04-25 Fix image filename case in README.md
2026-04-25 Clarify CAD file availability in README
    Updated CAD section to clarify file location.
2026-08-19 PCB added
2026-08-19 Update PCB directory structure in README
2026-08-19 added docs
    [BOM.csv]
2026-08-19 Fix image link and update PCB directory structure
    Updated image link format and changed PCB directory structure.
2026-08-20 Enhance README with detailed robot mechanics
    Refine the explanation of the robot's energy storage and landing recovery mechanisms for clarity and detail.
2026-08-20 Update ARM encoder wiring and status to active
